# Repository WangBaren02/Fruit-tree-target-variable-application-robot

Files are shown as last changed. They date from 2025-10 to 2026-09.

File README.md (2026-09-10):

# 果树对靶变量施药机器人

*Fruit Tree Targeted Variable-Rate Application Robot*

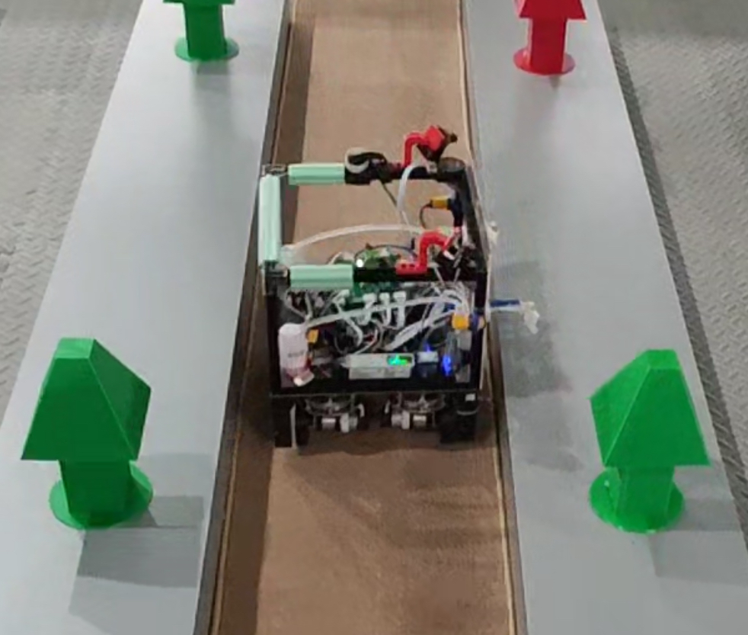
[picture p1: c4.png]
果树对靶变量施药机器人实机图片


## 项目简介

本项目面向果园植保作业场景，设计并实现了一套集自主移动、多传感器环境感知、目标视觉识别与变量施药于一体的农业机器人系统。系统采用 **STM32F407 + STM32F103 双控制器架构**：STM32F407 负责移动底盘、航向保持、行间运动与作业阶段调度，STM32F103 负责接收视觉/光电检测状态并驱动靶向施药机构。

移动底盘通过 **WitMotion IMU、6 路 Ultrasonic、Encoder 以及光电输入**获取姿态、环境距离、位移和行间状态，结合周期任务、作业状态机与 PID 完成前进、减速、换行和方向纠偏。作业端使用左右两个 OpenMV 脚本进行 **RGB565 图像采集、ROI 限定、颜色阈值分割和 Blob Detection**，将红/绿目标状态输出为 GPIO 信号；STM32F103 再根据作业侧、光电触发和目标颜色选择水泵组合及开启时间，实现面向目标类别的定时变量施药。

这个项目的核心不是把传感器简单堆叠在一块控制板上，而是把机器人拆分为三个相互协同的控制环节：

- **STM32F407**：解决机器人怎么移动、怎么保持方向、怎么减速和怎么换行；
- **OpenMV**：解决当前作业侧是否检测到红色/绿色目标；
- **STM32F103 + 水泵/舵机**：解决是否作业、对哪一侧作业以及采用哪一种施药时序。

## 项目亮点

- STM32F407 与 STM32F103 分工明确的双 MCU 分层控制；
- 基于 WitMotion 航向反馈、Ultrasonic 距离和 Encoder 位移的移动控制；
- TIM7 周期任务调度、`flag_step` 作业状态机和多组 PID 控制；
- OpenMV 基于颜色阈值、ROI 和最大 Blob 的轻量级目标识别；
- F407 通过 GPIO 状态信号向 F103 传递左右作业侧与作业使能状态；
- F103 使用光电边沿触发作业，并通过上下水泵的组合与开启时长区分红/绿目标的施药策略；
- 仓库同时保留自研 PCB 工程和 SolidWorks 机械设计资料。

## 技术栈与系统边界

| 子系统 | 已从工程中确认的实现 |
| --- | --- |
| 移动主控 | STM32F407VG、TIM7 周期调度、`flag_step` 状态机、PWM/GPIO |
| 作业控制器 | STM32F103RC、`WORK_FLAG`、左右选择、光电触发、泵/舵机控制 |
| 姿态/航向 | WitMotion 串口数据经 USART2 DMA 接收，解析 yaw；源码中的 `PID_9250_*` 为历史命名 |
| 距离感知 | 6 路 Ultrasonic：左/右侧各两路、前方两路 |
| 位移感知 | 当前 F407 软件初始化并读取 TIM3、TIM5 两路 Encoder 接口 |
| 光电输入 | F407 两路本地行间输入用于运动停行；F103 两路作业光电输入（PC4/PC9）用于目标经过触发 |
| 机器视觉 | 左、右两个 OpenMV 脚本；RGB565、QVGA、ROI、颜色阈值、最大 Blob |
| 底盘执行 | 4 路电机 PWM 与 4 路运动舵机输出 |
| 作业执行 | 1 路当前主循环使用的作业舵机输出、上下两路水泵、光电输入 |
| 工程资料 | PCB 工程压缩包、SolidWorks 零件/装配相关导出文件、STL/DWG/3MF 等 |

## 系统总体架构

```mermaid
flowchart TB
    env["果树目标与垄间环境"] --> perception["多源感知"]

    subgraph move["移动控制域 — STM32F407"]
        imu["WitMotion IMU<br/>USART2 DMA → yaw"]
        ultra["6 路 Ultrasonic"]
        enc["2 路 Encoder 接口"]
        localphoto["F407 光电输入"]
        f407logic["TIM7 周期任务<br/>flag_step 状态机 + PID"]
        imu --> f407logic
        ultra --> f407logic
        enc --> f407logic
        localphoto --> f407logic
        f407logic --> drive["4 路电机 PWM<br/>4 路运动舵机"]
    end

    subgraph vision["视觉感知域 — OpenMV"]
        leftcam["左 OpenMV 脚本"]
        rightcam["右 OpenMV 脚本"]
        visualgpio["红/绿 GPIO 状态"]
        leftcam --> visualgpio
        rightcam --> visualgpio
    end

    subgraph work["作业控制域 — STM32F103"]
        f103logic["WORK_FLAG + Select_LR<br/>Light_Detect + Select_Color"]
        strategy["红/绿目标施药策略"]
        workact["作业舵机<br/>上/下水泵"]
        f103logic --> strategy --> workact
    end

    perception --> imu
    perception --> ultra
    perception --> enc
    perception --> localphoto
    perception --> leftcam
    perception --> rightcam
    f407logic -- "PE7/PE8：左右作业侧<br/>PE14：作业使能" --> f103logic
    visualgpio -- "GPIO 红/绿状态" --> f103logic
    f103logic -- "PB7 → F407 PE15：减速反馈" --> f407logic
```

当前工程中，F407 与 F103 的实际协同路径是 GPIO 状态信号，而不是已经在主循环中启用的 UART 数据包协议：F407 使用 `PE7/PE8` 表示左右作业侧，使用 `PE14` 表示作业使能；F103 通过 `PB4/PB5/PB6` 读取这些状态，并通过 `PB7` 向 F407 回传减速信号。

## 双控制器协同架构

### STM32F407：移动底盘主控

F407 工程的 `USER/main.c` 完成底盘控制所需外设初始化，`SYSTEM/CONTROL/control.c` 中的 `TIM7_IRQHandler()` 负责周期性调度。当前源码可以恢复出以下职责链：

1. 通过 USART2 DMA 接收姿态串口帧，解析并更新 `yaw`；
2. 通过 6 路 Ultrasonic 获取前方和左右侧距离；
3. 通过 TIM3、TIM5 两路 Encoder 接口读取计数，并在换行流程中使用位移量；
4. 依据 `flag_step` 在前进、减速、左右转向、倒车和出垄等阶段之间切换；
5. 使用距离误差和 yaw 误差选择相应 PID，更新电机速度修正量与运动舵机角度；
6. 在不同作业阶段通过 `PE7/PE8` 选择左右作业侧，在需要时通过 `PE14` 打开作业模式；
7. 读取 F103 通过 `PB7 → PE15` 回传的减速信号，在检测到目标/作业触发后降低底盘速度。

源码中 `Select_Servo_Angle()`、`Select_Motor_Speed()`、`Select_PID()`、`HuanLong()` 和 `ChuLong()` 共同构成移动任务的状态化控制路径。这里的“换行/换垄”是由超声波、光电状态、航向控制和 Encoder 位移共同参与的流程，而不是单一传感器触发的动作。

### STM32F103：靶向施药控制器

F103 工程的 `USER/main.c` 在 `WORK_FLAG` 有效时执行：

```text
WORK_FLAG
  → Select_LR()
  → Light_Detect()
  → servo1(0)
```

其中：

- `Select_LR()` 对 F407 传来的左右作业侧信号进行两次采样确认，形成 `flag_Left/flag_Right`；
- `Light_Detect()` 监测作业板上的左右光电输入，在目标经过时触发一次作业；
- `Select_Color()` 只读取当前作业侧对应的红/绿输入，并形成 `flag_Red/flag_Green`；
- `Water()` 根据目标颜色选择上下水泵的开启组合与持续时间；
- `Clear_RESET()` 在非作业阶段清除颜色状态、复位光电基准并关闭水泵；
- `servo1()` 是当前主循环实际调用的作业舵机位置输出，非作业状态调用 `servo1(270)`，作业状态调用 `servo1(0)`。

因此，F103 不是另一个独立的移动主控，而是一个围绕“作业侧选择—目标触发—施药执行”展开的专用控制器。

### F407 ↔ F103 板间信号

| 逻辑信号 | F407 端 | F103 端 | 代码语义 |
| --- | --- | --- | --- |
| 左作业侧 | `PE7` | `PB4` | `Left_Flag` |
| 右作业侧 | `PE8` | `PB5` | `Right_Flag` |
| 作业使能 | `PE14` | `PB6` | `WORK_FLAG` |
| 减速反馈 | `PE15` | `PB7` | `SlowDown`，由 F103 回传给 F407 |

`Detect_Flag_Mv()` 根据 F407 当前的 `flag_step` 设置左右作业侧信号；`HuanLong()` 在换行作业阶段拉高作业使能；F103 在光电检测到目标后拉高减速输出，F407 的 `Detect_Flag_Slowdown()` 再据此进入减速逻辑。当前代码能够确认的是这组 GPIO 级状态协同，不应把它包装成复杂的双向通信协议。

## 移动底盘控制

### 周期任务与状态机

F407 的 TIM7 中断以周期计数方式组织任务：5 ms 级别执行检测、减速判断、舵机角度选择、电机速度选择和 PID 选择；25 ms 级别触发 Ultrasonic；10 ms 级别发送 yaw 相关数据。`flag_step` 将整车动作拆分为前进、光电停行、左右换行、倒车和出垄等阶段。

### 航向、距离与位移反馈

- **WitMotion 航向反馈**：`HARDWARE/USART2_DMA/usart2_dma.c` 从 USART2 DMA 缓冲区解析 `0x55 0x53` 姿态帧，得到相对起始航向的 `yaw`；
- **距离反馈**：`HARDWARE/ULTRASONIC/` 中维护 `ultra_L1/L2`、`ultra_R1/R2`、`ultra_F1/F2` 六路测距量，并在不同运动阶段选择侧向或前向距离误差；
- **位移反馈**：`HARDWARE/ENCODER/` 当前初始化 TIM3、TIM5 两个 Encoder 接口，`Read_Encoder_Cnt()` 将计数换算为 `Encoders.disA/disB`，主要服务于换行/倒车距离流程；
- **执行输出**：`HARDWARE/MOTOR/` 提供 4 路电机 PWM 与方向控制，`HARDWARE/SERVO/` 当前运动路径使用 4 路舵机 PWM。

旧版说明中的“6 encoders”没有得到当前 F407 软件读取路径的支持。README 采用源码能确认的“两路 Encoder 接口”，不把可能存在的机械配置数量与软件实际读取数量混为一谈。

### 移动控制闭环

```mermaid
flowchart LR
    imu["WitMotion yaw"] --> heading["航向误差 / PID"]
    ultra["6 路 Ultrasonic"] --> distance["距离误差 / PID"]
    enc["TIM3 + TIM5 Encoder"] --> row["换行位移判断"]
    heading --> control["运动控制策略"]
    distance --> control
    row --> control
    control --> output["4 路电机 PWM<br/>4 路运动舵机"]
    output --> robot["移动底盘"]
    robot -. "姿态/距离/位移反馈" .-> imu
    robot -. "姿态/距离/位移反馈" .-> ultra
    robot -. "姿态/距离/位移反馈" .-> enc
```

## 靶向变量施药

### 变量由什么控制

当前源码所体现的“变量”不是由流量传感器构成的连续流量闭环，而是由以下离散策略共同决定：

1. **目标类别**：OpenMV 输出红色或绿色状态；
2. **作业侧**：F407 通过 `PE7/PE8` 告知 F103 当前执行左侧还是右侧机构；
3. **触发时刻**：F103 的左右光电输入检测到目标经过的边沿后启动一次作业；
4. **泵组合与开启时间**：`Water()` 按红/绿状态控制上、下两路水泵及其延时常量。

在当前 `sow.c` 中，代码逻辑可以概括为：

| 目标状态 | 当前代码中的执行策略 |
| --- | --- |
| 绿色 | 下路水泵开启，保持 `BiuBiu_time_Green` 对应的延时后关闭 |
| 红色 | 上路水泵先开启 `BiuBiu_time_UP` 对应的延时，再开启下路水泵并保持 `BiuBiu_time_DOWN` 对应的延时 |

因此，本项目的变量施药应准确表述为：**基于目标颜色分类的双水泵组合与定时控制**。代码中没有发现流量传感器、压力反馈或基于 Blob 面积连续调节泵时长的闭环；Blob 面积在 OpenMV 中用于筛选有效目标和选取最大 Blob，当前并未直接映射为施药量。

### 靶向施药控制流程

```mermaid
flowchart TD
    camera["左/右 OpenMV"] --> image["RGB565 图像 + ROI"]
    image --> blob["颜色阈值 + Blob Detection<br/>选取最大 Blob"]
    blob --> color["红/绿 GPIO 状态"]

    side["F407 PE7/PE8<br/>左右作业侧"] --> f103["STM32F103"]
    workflag["F407 PE14 → PB6<br/>WORK_FLAG"] --> f103
    color --> f103
    photo["F103 PC4/PC9<br/>左右光电输入"] --> edge["Light_Detect 光电边沿"]
    f103 --> edge
    edge --> select["Select_LR + Select_Color"]
    select --> delay["按作业侧等待<br/>Deteted2Biu_Left/Right"]
    delay --> strategy{"目标类别"}
    strategy -->|绿色| green["Pump_Down<br/>按 Green 时长开启"]
    strategy -->|红色| red["Pump_Up → Pump_Down<br/>按 UP/DOWN 时长顺序开启"]
    green --> clear["关闭水泵并清除本次状态"]
    red --> clear
    f103 -. "PB7 SlowDown" .-> slow["F407 PE15<br/>底盘减速"]
```

## 机器视觉

仓库中的 `OpenMV/left.txt` 和 `OpenMV/rught.txt` 分别对应左、右作业侧脚本。两份脚本的当前有效路径具有相同的基本结构：

- 使用 `RGB565`、`QVGA` 图像格式，并关闭自动增益和自动白平衡；
- 只在预设 ROI 内搜索目标，减少整幅图像处理范围；
- 使用绿色和红色 Color Threshold 查找 Blob；
- 以 `pixels()` 选择面积最大的候选 Blob；
- 将绿色/红色识别结果通过 GPIO 输出给 F103 的输入端。

当前有效代码不是神经网络、YOLO 或深度学习模型。脚本中虽然保留了 UART 导入和“双目标”相关的注释/变量，但当前工作路径实际使用的是红/绿 GPIO 状态；`double` 输出逻辑没有形成已启用的独立目标类别。

## 自动作业流程

```text
F407 进入对应 flag_step
        ↓
通过 PE7 / PE8 告知 F103 当前左右作业侧
        ↓
在作业阶段通过 PE14 置位 WORK_FLAG
        ↓
F103 读取当前侧 OpenMV 红/绿 GPIO 状态
        ↓
左右光电输入出现目标经过边沿
        ↓
按作业侧延时后执行 Select_Color / Water
        ↓
根据红/绿状态选择上下水泵组合和开启时间
        ↓
F103 通过 PB7 回传减速状态，F407 降低底盘速度
        ↓
关闭水泵、清除本次状态，等待下一目标
```

## 硬件与机械设计

仓库同时包含机器人硬件和机械设计资料：

- `第十届农装PCB工程.epro`：PCB 工程压缩包，内部包含多份 PCB 布局、原理图、封装和符号资源；
- `SW文件/`：包含相机支架、超声波支架、树体/亚克力结构、施药机构以及齿轮、链条、舵机等相关机械设计或导出文件；
- `c4.png`：现有机器人实机/比赛场景图片。

本 README 只描述能够从工程结构和源码中确认的系统关系，不把无法从当前资料完整核实的电路细节、喷头流量或机械尺寸扩展成性能结论。

## 软件结构

目录保持仓库原有组织方式，未对源码进行移动、重命名或重构：

```text
.
├── 正赛主控代码/        # STM32F407 移动底盘主控工程
│   ├── CORE/
│   ├── DMP/
│   ├── FWLIB/
│   ├── HARDWARE/
│   ├── SYSTEM/
│   └── USER/
├── 正赛作业代码/        # STM32F103 靶向施药控制工程
│   ├── CORE/
│   ├── HARDWARE/
│   ├── STM32F10x_FWLib/
│   ├── SYSTEM/
│   └── USER/
├── OpenMV/              # 左/右视觉脚本
├── SW文件/              # 机械设计及导出资料
├── 第十届农装PCB工程.epro # PCB 工程
├── c4.png              # 实机图片
├── README.md
└── LICENSE
```

### F407 工程模块

- `USER/`：启动入口和主循环；
- `SYSTEM/CONTROL/`：TIM7 周期调度、移动任务状态机、行间动作和作业板信号；
- `SYSTEM/PID/`：距离/航向等运动控制器；
- `HARDWARE/MOTOR/`：4 路电机 PWM 与方向控制；
- `HARDWARE/SERVO/`：运动舵机 PWM；
- `HARDWARE/ENCODER/`：TIM3/TIM5 Encoder 接口和位移读取；
- `HARDWARE/ULTRASONIC/`：6 路 Ultrasonic 触发、捕获和滤波；
- `HARDWARE/USART2_DMA/`：姿态串口 DMA 接收与 yaw 解析；
- `HARDWARE/IO/`：本地光电输入及 F407/F103 板间 GPIO。

### F103 工程模块

- `USER/`：作业控制主循环；
- `HARDWARE/SOW/`：左右选择、颜色判断、光电触发、泵控制、作业状态清理；
- `HARDWARE/IO/`：OpenMV 红/绿输入、光电输入、泵输出及板间信号；
- `HARDWARE/PWM/`：作业舵机 PWM；
- `HARDWARE/TIMER/`、`HARDWARE/KEY/`：定时和按键/调试相关功能；
- `HARDWARE/UART/`：仓库中保留的 OpenMV 串口解析模块，当前 `main.c` 未将其接入有效作业主流程。

## 项目演示

[▶ 点击观看果树对靶变量施药机器人实机演示](https://www.bilibili.com/video/BV1MZybBGE1s?vd_source=f2363d1b121157b15409b799183edefd)

## 比赛背景

本项目对应 **“天鹅杯”第十届国际大学生智能农业装备创新大赛 B 类（机器人类）** 的果树对靶变量施药机器人作品。比赛背景资料可参见：[“天鹅杯”第十届国际大学生智能农业装备创新大赛通知](https://uiaec.ujs.edu.cn/news_show.php?id=215)。

## 实现边界与历史命名说明

- F407 工程中存在 `MPU9250`、`MPUIIC`、DMP 以及 `PID_9250_*` 等历史目录、宏和函数名；当前 README 按实际机器人使用的 **WitMotion IMU** 及 `USART2_DMA` 的 yaw 解析路径描述，不修改这些历史命名；
- F407 工程还保留 `wit_c_sdk`、TFLuna 等模块，但它们不能仅凭存在于目录中就视为当前主控制链路的一部分；
- F103 工程保留 TCS3200、JAINSU 以及 OpenMV UART 帧解析等旧/备用模块，当前有效作业主循环使用的是 GPIO 红/绿输入和光电输入；
- 仓库中的历史代码、注释、备用模块和旧工程配置均未在本次工作中清理或重构。

## License

本项目许可证信息请参见仓库中的 [`LICENSE`](./LICENSE) 文件。

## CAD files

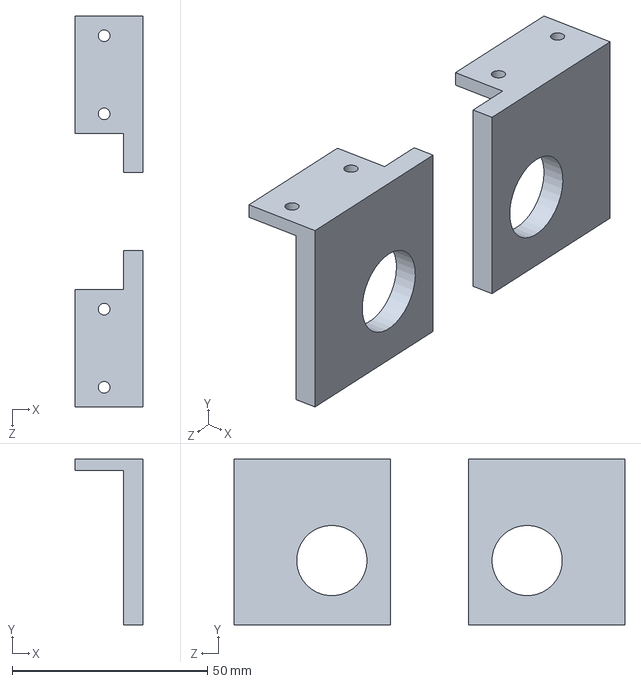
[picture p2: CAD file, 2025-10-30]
SW文件/光电管/光电管支架1cm.SLDPRT
17.5 x 42.5 x 100.0 mm

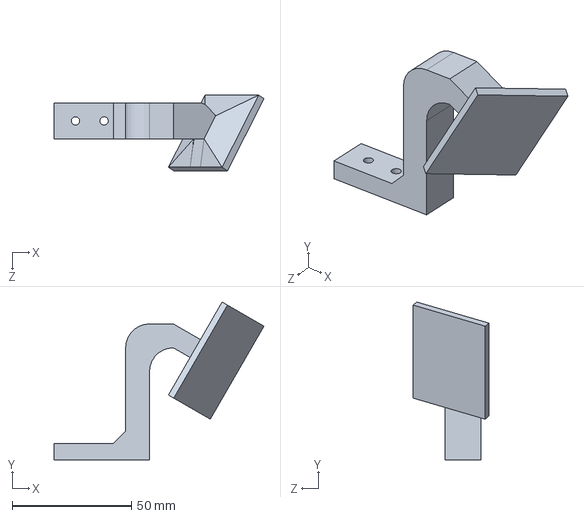
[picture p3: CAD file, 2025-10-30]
SW文件/摄像头（不可调）/摄像头左.SLDPRT
88.0 x 66.2 x 31.7 mm

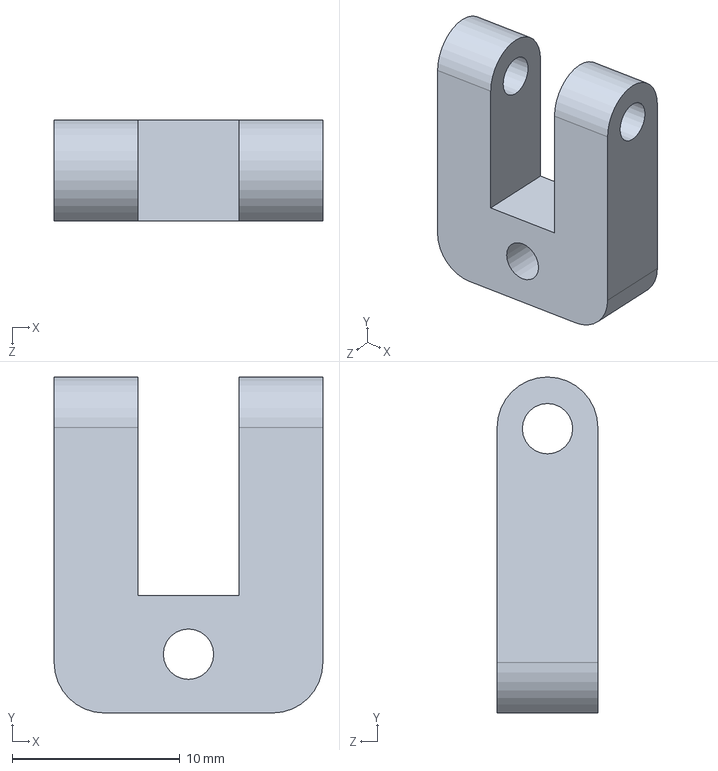
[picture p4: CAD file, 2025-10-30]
SW文件/摄像头（可调）/摄像头支架.SLDPRT
16.0 x 20.0 x 6.00 mm

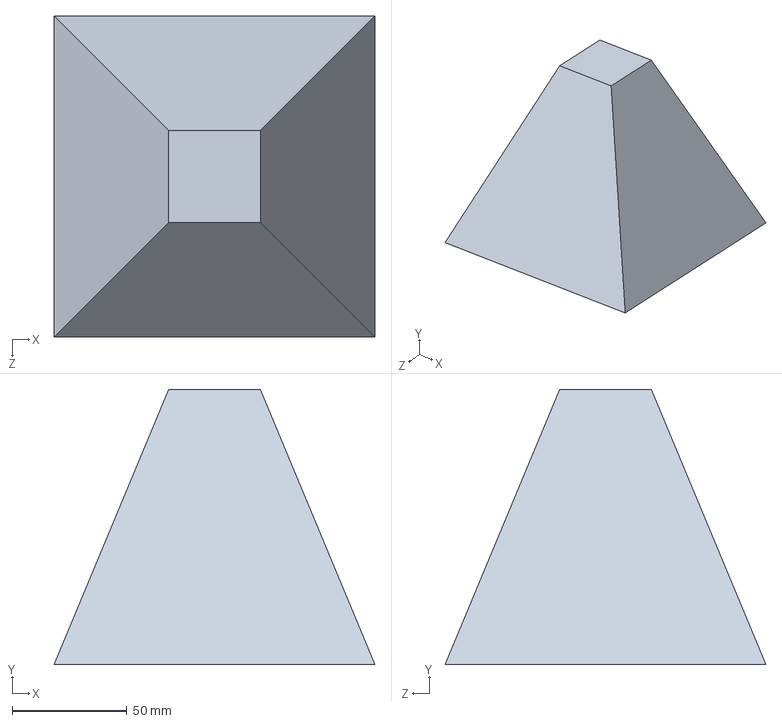
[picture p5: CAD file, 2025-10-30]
SW文件/树/树冠.SLDPRT
140.0 x 120.0 x 140.0 mm

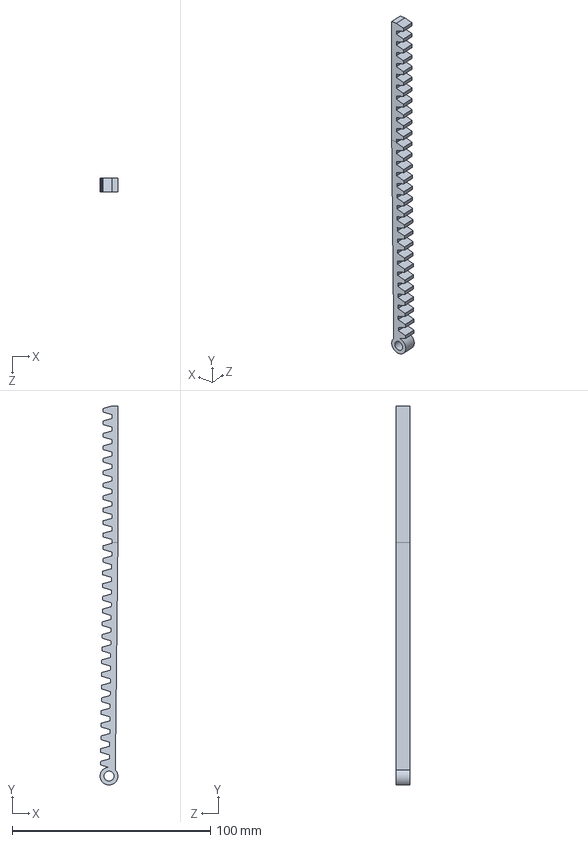
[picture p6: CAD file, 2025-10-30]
SW文件/线性执行器/链条.SLDPRT
8.99 x 191.3 x 7.00 mm

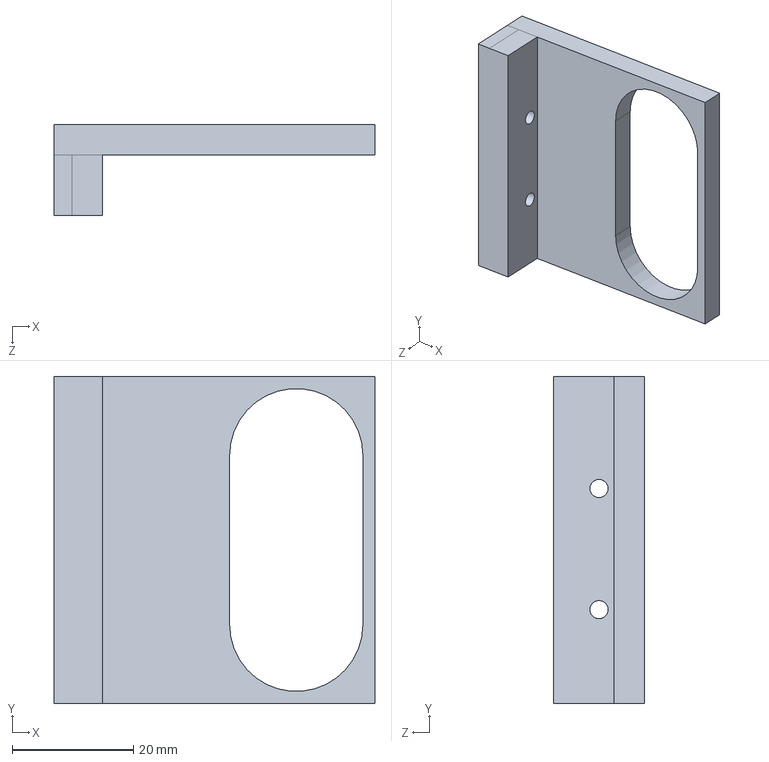
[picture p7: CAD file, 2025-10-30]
SW文件/超声波支架/超声波支架前1.SLDPRT
53.0 x 54.0 x 15.0 mm

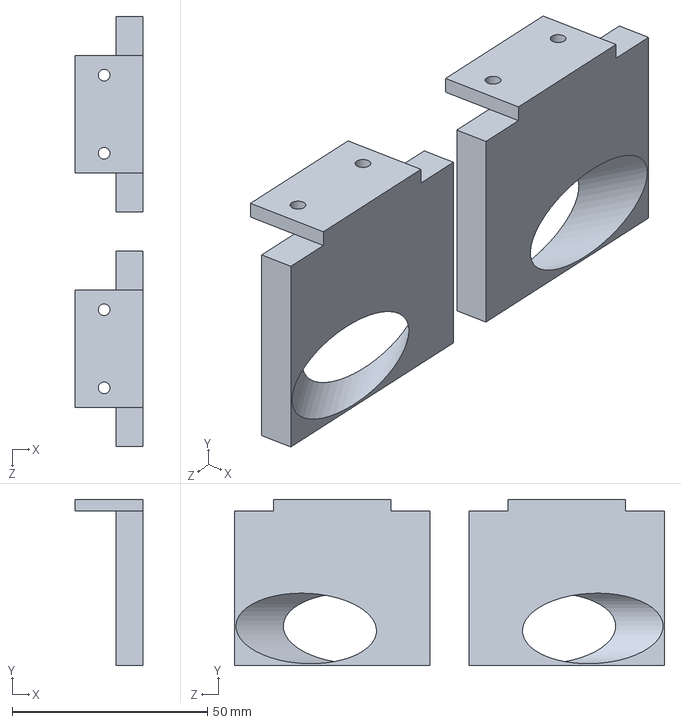
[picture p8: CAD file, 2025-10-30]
SW文件/光电管/光电管支架 60°椭圆.SLDPRT
17.5 x 42.5 x 110.0 mm

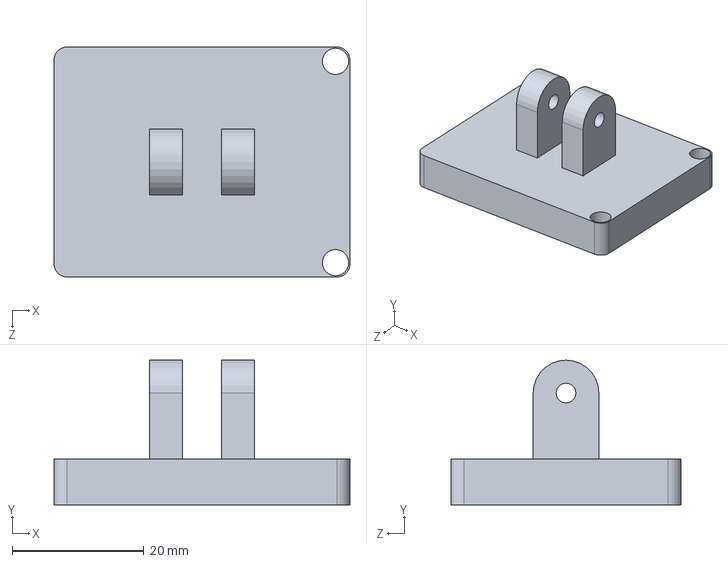
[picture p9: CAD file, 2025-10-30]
SW文件/摄像头（可调）/摄像头支架2.SLDPRT
45.0 x 22.0 x 35.0 mm

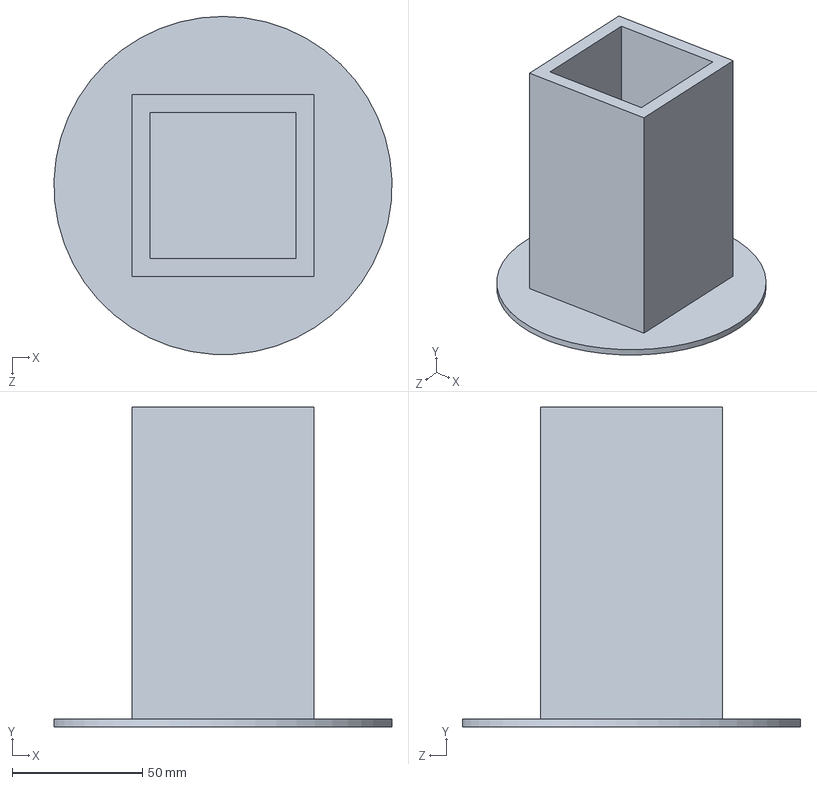
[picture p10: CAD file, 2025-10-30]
SW文件/树/树干.SLDPRT
129.9 x 123.0 x 130.0 mm

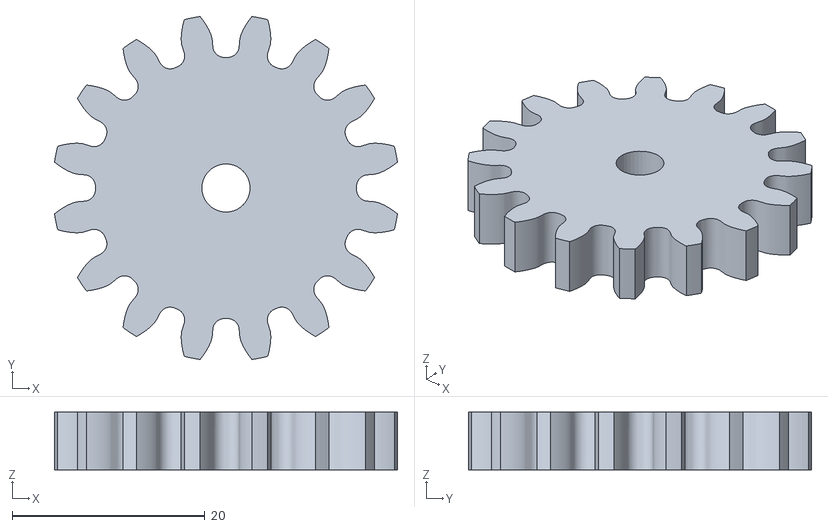
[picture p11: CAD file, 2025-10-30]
SW文件/线性执行器/齿轮小.STL
35.6 x 35.6 x 6.00

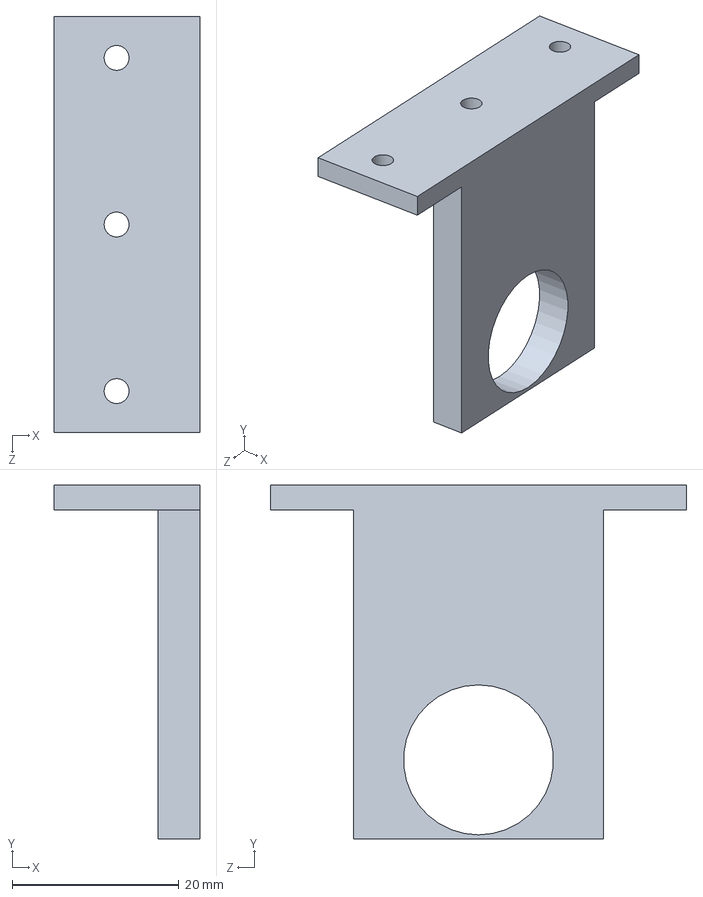
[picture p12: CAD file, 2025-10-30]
SW文件/光电管/光电管支架2.SLDPRT
17.5 x 42.5 x 50.0 mm

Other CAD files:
SW文件/不锈钢底板/不锈钢底板1.SLDPRT
SW文件/亚克力板/喷头亚克力板.SLDPRT
SW文件/不锈钢底板/不锈钢底板.SLDPRT
SW文件/亚克力板/圆盘.DWG
SW文件/摄像头（不可调）/摄像头右.SLDPRT
SW文件/超声波支架/超声波支架前2.SLDPRT
SW文件/亚克力板/亚克力左.SLDPRT
SW文件/亚克力板/不锈钢底板.DWG
SW文件/亚克力板/不锈钢底板.SLDPRT
SW文件/亚克力板/亚克力右.DWG
SW文件/亚克力板/亚克力右.SLDPRT
SW文件/亚克力板/亚克力左.DWG
SW文件/亚克力板/亚克力板.DWG
SW文件/亚克力板/亚克力板.SLDPRT
SW文件/亚克力板/喷头亚克力板.DWG
SW文件/光电管/光电管支架 - 副本 - 副本 - 副本.SLDPRT
SW文件/光电管/光电管支架 - 副本 - 副本.SLDPRT
SW文件/光电管/光电管支架 45°.SLDPRT
SW文件/光电管/光电管支架 45°.STL
SW文件/光电管/光电管支架 45°2 - 副本.SLDPRT
SW文件/光电管/光电管支架 45°2.SLDPRT
SW文件/光电管/光电管支架 45°2.STL
SW文件/光电管/光电管支架 45°椭圆.SLDPRT
SW文件/光电管/光电管支架 45°椭圆.STL
SW文件/光电管/光电管支架 60°椭圆.STL
SW文件/光电管/光电管支架1cm.STL
SW文件/光电管/光电管支架2.3mf
SW文件/光电管/光电管支架2.STL
SW文件/光电管/光电管支架2cm.SLDPRT
SW文件/光电管/光电管支架2cm.STL
SW文件/光电管/光电管支架短.STL
SW文件/光电管/光电管支架长.STL
SW文件/摄像头（不可调）/摄像头右.STL
SW文件/摄像头（不可调）/摄像头左.STL
SW文件/摄像头（可调）/摄像头支架.STL
SW文件/摄像头（可调）/摄像头支架2.STL
SW文件/树/树冠.STL
SW文件/树/树冠2.STL
SW文件/树/树干.STL
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

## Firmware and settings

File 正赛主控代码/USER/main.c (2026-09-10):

#include "stdio.h"
#include "string.h"
#include "sys.h"
#include "delay.h"
#include "stm32f4xx.h"
#include "control.h"
//#include "lamp.h"
#include "led.h"
#include "beep.h"
#include "key.h"
#include "oled.h"
#include "usart1_dma.h"
#include "usart2_dma.h"
#include "usart3_dma.h"
#include "uart4_dma.h"
#include "timer7.h"
#include "servo.h"
#include "ultrasonic.h"
#include "motor.h"
#include "encoder.h"
#include "pid.h"
#include "io.h"

float start_yaw=0;

int main(void)
{
	//系统初始化
	u8 key;
	u8 Add_Encoder_Flag = 0;
	float Add_Encoder_Oled = 0;
	float yaw_t;
	NVIC_PriorityGroupConfig(NVIC_PriorityGroup_2);
	delay_init(168);
	//BEEP_Init();
	Key_Init();
	IO_init();
	LED_Init();
	TIM4_Servo_PWM_Init(20000,84);
	Ultrasonic_Init();
	OLED_Init();
	OLED_Display_On();
	
	OLED_Clear();
	Motor_Init();
	TIM7_Init(1000,84);
	TIM3_EncoderB_Init(0xFFFF,1);
	TIM5_EncoderA_Init(0xFFFF,1);
	PID_Init();
	Motor_Stop();
	Motor_Set_Speed();
	USART1_Init(115200);	//单片机与陀螺仪上位机通讯串口
	USART2_Init(9600);		//单片机与陀螺仪通讯串口

	Servo1_Increase = 0;
	Servo2_Increase = 0;
	Servo3_Increase = 0;
	Servo4_Increase = 0;
	SpeedL1_Increase = 0;
	SpeedR1_Increase = 0;
	SpeedL2_Increase = 0;
	SpeedR2_Increase = 0;
	SpeedL1_Increase_9250 = 0;
	SpeedR1_Increase_9250 = 0;
	SpeedL2_Increase_9250 = 0;
	SpeedR2_Increase_9250 = 0;
//	LED1_ON;
	
	Servo_Forw();
//	Servo_Turn();
	Servo_Set_Angle();
	while(1)
	{
		key = Key_Scan();
		if(key == 1)	//尽量不要改里面的东西，看懂了再改
		{
			start_YAW=yaw;					//记录下当前指南针原始中心角度
			if(start_YAW>-180 && start_YAW<-135) mode=2;
			else if(start_YAW<180 && start_YAW>135) mode=3;

			delay_ms(100);			//等待yaw稳定
			
			start_yaw=yaw;
			PID_9250_Forward_motor.desired = start_yaw;
			PID_9250_Forward.desired = start_yaw;
			PID_9250_Right.desired = start_yaw;
			PID_9250_Left.desired = start_yaw;
			PID_9250_Right_slow.desired = start_yaw;
			PID_9250_Left_slow.desired = start_yaw;
			PID_9250_Back.desired = start_yaw;
			PID_9250_Back_last.desired = start_yaw;
			PID_9250_Back_last_motor.desired = start_yaw;
			
			GPIO_ResetBits(GPIOE,GPIO_Pin_14);	//板间通讯，给作业板关闭作业模式信号
			
			flag_mission_start = 1;
			flag_delay_1500ms = 1;	//step0时开始2s后以75%速度继续行驶
		}
		
		if(key == 2)
		{
//			switch (Add_Encoder_Flag)
//			{
//				case 1: Add_Encoder_2 	+= 1.8; Add_Encoder_Oled += 1.8; break;
//				case 2: Add_Encoder_4 	+= 1.6; Add_Encoder_Oled += 1.6; break;
//				case 3: Add_Encoder_6 	+= 1.8; Add_Encoder_Oled += 1.8; break;
//				case 4: Add_Encoder_8 	+= 1.6; Add_Encoder_Oled += 1.6; break;
//				case 5: Add_Encoder_10 	+= 1.8; Add_Encoder_Oled += 1.8; break;
//				case 6: Add_Encoder_Last+= 2.0; Add_Encoder_Oled += 2.0; break;
//				default:;
//			}
////调编码器用		
//			switch (Add_Encoder_Flag)
//			{
//				case 1: Add_Encoder_2 	-= 0.3; Add_Encoder_Oled -= 0.3; break;
//				case 2: Add_Encoder_4 	-= 0.2; Add_Encoder_Oled -= 0.2; break;
//				case 3: Add_Encoder_6 	-= 0.3; Add_Encoder_Oled -= 0.3; break;
//				case 4: Add_Encoder_8 	-= 0.2; Add_Encoder_Oled -= 0.2; break;
//				case 5: Add_Encoder_10 	-= 0.3; Add_Encoder_Oled -= 0.3; break;
//				case 6: Add_Encoder_Last-= 1.0; Add_Encoder_Oled -= 1.0; break;
//				default:;
//			}
			
			switch (Add_Encoder_Flag)
			{
				case 1: Add_Encoder_2 	+= 0.3; Add_Encoder_Oled += 0.3; break;
				case 2: Add_Encoder_4 	+= 0.2; Add_Encoder_Oled += 0.2; break;
				case 3: Add_Encoder_6 	+= 0.3; Add_Encoder_Oled += 0.3; break;
				case 4: Add_Encoder_8 	+= 0.2; Add_Encoder_Oled += 0.2; break;
				case 5: Add_Encoder_10 	+= 0.3; Add_Encoder_Oled += 0.3; break;
				case 6: Add_Encoder_Last+= 1.0; Add_Encoder_Oled += 1.0; break;
				default:;
			}
			
//			PID_F1_Right_Servo.kd +=0.1;
//			PID_F2_Right_Servo.kd +=0.1;
//			PID_F1_Right_Servo.kd += 0.1;
//			PID_F2_Right_Servo.kd += 0.1;
//			flag_step += 2;
//			PID_9250_Right.kd+=100;
//			PID_F1_Left_Servo.kp+=0.1;
//			PID_F1_Left_Servo.kp+=0.1;
		}
		
		if(key == 3)
		{
			if(Add_Encoder_Flag < 6)
			{
				Add_Encoder_Flag ++;
			}
			else if(Add_Encoder_Flag == 6)
			{
				Add_Encoder_Flag = 0;
			}
			Add_Encoder_Oled = 0; 
//			PID_9250_Right.kd+=50;
//			PID_F1_Right_Servo.kd +=0.05;
//			PID_F2_Right_Servo.kd +=0.05;
//			PID_F1_Right_Servo.kd += 0.05;
//			PID_F2_Right_Servo.kd += 0.05;
//			start_YAW=yaw;					//记录下当前指南针原始中心角度
//			if(start_YAW>-180 && start_YAW<-135)mode=2;
//			else if(start_YAW<180 && start_YAW>135)mode=3;
//			PID_9250_Right.kd+=2;
		}
		
		if(key == 4)
		{
			switch (Add_Encoder_Flag)
			{
				case 1: Add_Encoder_2 	+= 0.8; Add_Encoder_Oled += 0.8; break;
				case 2: Add_Encoder_4 	+= 0.55; Add_Encoder_Oled += 0.55; break;
				case 3: Add_Encoder_6 	+= 0.8; Add_Encoder_Oled += 0.8; break;
				case 4: Add_Encoder_8 	+= 0.55; Add_Encoder_Oled += 0.55; break;
				case 5: Add_Encoder_10 	+= 0.8; Add_Encoder_Oled += 0.8; break;
				case 6: Add_Encoder_Last+= 2.0; Add_Encoder_Oled += 2.0; break;
				default:;
			}
//			PID_9250_Right.kd+=10;
//			PID_F1_Right_Servo.kd +=0.01;
//			PID_F2_Right_Servo.kd +=0.01;
//			PID_F1_Right_Servo.kd += 0.01;
//			PID_F2_Right_Servo.kd += 0.01;
//			delay_ms(100);
//			Motor_Forw();
//			Motor_Right();
//			Motor_Left();
//			Motor_Back();
//			Motor_Set_Speed();
//			Servo_Forw();
//			Servo_Set_Angle();
		}
		
		
		delay_us(20);
//		OLED_Show3FNum(10,0,yaw ,4,2,12);
//		OLED_ShowIntNum(64,0,flag_step,2,12);
		//OLED_ShowIntNum(84,0,flag_huanlong,1,12);
		//OLED_ShowIntNum(96,0,flag_chulong,1,12);
		
//		OLED_Show3FNum(64,0 ,	PID_9250_Back.kp,3,1,12);
//		OLED_Show3FNum(10,12 ,	PID_9250_Back.kd,3,1,12);
		
		
//		OLED_Show3FNum(0,36,PID_9250_Right.kp,5,2,12);
//		OLED_Show3FNum(48,36,PID_9250_Right.kd,5,2,12);
/*********************************************************/
		OLED_Show3FNum(60,36,ultra_F1.DIS ,5,2,12);	//接口5
		OLED_Show3FNum(0,36,ultra_F2.DIS ,5,2,12);	//接口6

		OLED_Show3FNum(60,24,ultra_L1.DIS ,5,2,12);	//接口1
		OLED_Show3FNum(60,12,ultra_L2.DIS,5,2,12);	//接口2
		
		OLED_Show3FNum(0,24,ultra_R1.DIS ,5,2,12);	//接口3
		OLED_Show3FNum(0,12,ultra_R2.DIS ,5,2,12);	//接口4
		
//		OLED_Show3FNum(0,48,PID_F1_Right_Servo.kp ,5,2,12);
//		OLED_Show3FNum(60,48,PID_F1_Right_Servo.kd ,5,2,12);
		OLED_Show3FNum(0,48,Add_Encoder_Flag ,5,2,12);
		OLED_Show3FNum(60,48,Add_Encoder_Oled ,5,2,12);
    
//		OLED_Show3FNum(10,48,RightLightLast ,1,0,12);
//		OLED_Show3FNum(24,48,LeftLightLast ,1,0,12);
//		OLED_Show3FNum(36,48,RightLight ,1,0,12);
//		OLED_Show3FNum(48,48,LeftLight ,1,0,12);
//		OLED_Show3FNum(10,48,PID_F1_Left_Servo.kp ,1,3,12);
//		OLED_Show3FNum(48,48,PID_F1_Left_Servo.kd ,1,3,12);
	  OLED_Refresh_Gram();
	}
}

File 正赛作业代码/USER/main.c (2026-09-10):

#include "delay.h"
#include "sys.h"
#include "bmp.h"
#include "stdio.h"
#include "io.h"
#include "pwm.h"
#include "timer.h"
#include "key.h"
#include "sow.h"

int main(void)
{
		u8 key;
		IO_Init();
	  NVIC_PriorityGroupConfig(NVIC_PriorityGroup_2);   //设置NVIC中断分组2:2位抢占优先级，2位响应优先级
		TIM5_PWM_Init(20000,72);
		delay_init();	 //延时函数初始化:	有问题，延迟时间大概是八分之一，最长24000（3s） 

			while(1)
			{
				key = KEY_Scan(0);

				//正式比赛
				if(WORK_FLAG)
				{
					Select_LR();
					Light_Detect();
					servo1(0);
				}
				else
				{
					Clear_RESET();
					servo1(270);
				}
				
				
				 //摄像头颜色测试				
         if ((Right_red) && (!Right_green))
				 {
						Led1_ON;  
						Led2_ON;  
				 }
				 else if ((!Right_red) && (Right_green))
				 {
						Led1_ON;  
				 }
				 else
				 {
						Led1_OFF;  
						Led2_OFF; 
				 }
				
//				//舵机测试				
//				if(key == KEY_B9_PRES)
//				{
//					servo1(270);
//					Led1_ON;
//				}
//				
//				if(key == KEY_C13_PRES)
//				{
//					servo1(0);
//					Led1_OFF;
//				}
				
				//喷水测试				
				if(key == KEY_B9_PRES)
				{
//					Pump_Down_ON;								//开启下水泵
//					Pump_Up_ON;									//开启上水泵
//								
//					delay_ms(BiuBiu_time_UP);		//下水泵喷水时长
//					Pump_Down_OFF;							//关闭下水泵
//							
//					delay_ms(BiuBiu_interval);	//上水泵多于下水泵的喷水时长
//					Pump_Up_OFF;								//关闭上水泵
					
					
					Pump_Down_ON;									//开启下水泵
					delay_ms(BiuBiu_time_Green);	//下水泵喷水时长
					Pump_Down_OFF;								//关闭下水泵
				}
				
				if(key == KEY_C13_PRES)
				{
//					Pump_Up_ON;		//上水泵
//					Pump_Down_ON;;	//下水泵
//					delay_ms(200);	//上：8~9
//					Pump_Up_OFF;	//关闭上水泵
//					Pump_Down_OFF;							//关闭下水泵
////					Pump_Up_ON;			//上水泵
////					Pump_Down_ON;;	//下水泵
//					
//					
//					
					Pump_Up_ON;									//开启上水泵
					delay_ms(BiuBiu_time_UP);		//下水泵喷水时长
					Pump_Up_OFF;								//关闭下水泵
				}
				
//				//光电管测试
//				if(Light_Left)	//左侧光电管
//					Led1_ON;
//				else
//					Led1_OFF;
//				
//				if(Light_Right)	//右侧光电管
//					Led2_ON;
//				else
//					Led2_OFF;

//				//左右行检测				
//				if(flag_Right) Led1_ON;
//				else Led1_OFF;
//				
//				if(flag_Left) Led2_ON;
//				else Led2_OFF;
			
			}
}

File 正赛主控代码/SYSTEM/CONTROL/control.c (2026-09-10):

/*
2025 张瀚文
		        F1 头 F2
			   L1----------R1
				 |            |
				 |            |
				 |            |
				 |            |
				 |            |
				 |            |
				 |            |
				 |            |
				 |            |
				 L2---------- R2
				       尾 
*/
#include "stdio.h"
#include "string.h"
#include "control.h"
#include "sys.h"
#include "delay.h"
//#include "lamp.h"
#include "led.h"
#include "usart1_dma.h"
#include "usart2_dma.h"
#include "usart3_dma.h"
#include "uart4_dma.h"
#include "ultrasonic.h"
#include "oled.h"
#include "encoder.h"
#include "param.h"
#include "motor.h"
#include "pid.h"
#include "servo.h"
#include "io.h"

#define N 0.98
#define Move 180          //直行停车预留量 160
#define move 320          //右行停车预留量 320
#define movez 320         //左行停车预留量 320
#define movez_last 240		//出垄前左行停车预留量

u8 parity	= 0;								//判断奇数偶
float pitch, roll;
extern float yaw;
short aacx, aacy, aacz;
short gyrox, gyroy, gyroz;
u8 flag_step = 0;					//判断现在运行到了第几步的标志
u8 flag_yaw_new = 0;
float Add_Encoder_2 					= 0;
float Add_Encoder_4 					= 0;
float Add_Encoder_6 					= 0;
float Add_Encoder_8 					= 0;
float Add_Encoder_10 					= 0;
float Add_Encoder_Last 				= 0;

char PIDOUT[20];
//int a=0;
/***********************************张瀚文 2024********************************************
0： 入长垄          
1： 右行
2： 换垄
3： 左行
4： 换垄
5： 右行
6： 换垄
7： 左行
8： 换垄
9： 右行
10：换垄
11：左行
12：出垄
13：停车
***********************************************************************************************/
u8 flag_mission_start 		= 0;				//按键按下后，进入控制函数的标志
u8 flag_huanlong 				  = 0;				//换垄标志，此flag=1时正在换垄
u8 flag_chulong 				  = 0;				//出笼标志，此flag=1时已经出笼
u8 flag_slowdown 				  = 0;				//减速标志，此flag=1时表示需要减速
u8 flag_zuowuslowdown 		= 0;				//减速标志，此flag=1时表示需要减速
u8 flag_found_zuowu				= 0;				//检测作物的标志，此flag=1时表示检测到作物，开始减速
u8 flag_delay					    = 0;				//延时标志，此flag=1时表示需要延时
u8 flag_delay_200ms				= 0;				//延时标志，此flag=1时表示需要延时200ms
u8 flag_delay_500ms				= 0;				//延时标志，此flag=1时表示需要延时500ms
u8 flag_delay_1000ms			= 0;				//延时标志，此flag=1时表示需要延时1000ms
u8 flag_delay_1500ms			= 0;				//延时标志，此flag=1时表示需要延时1500ms
u8 flag_delay_zuowu				= 0;				//延时标志，此flag=1时作物表示需要延时
u8 Color_SLOW							= 0;
u8 flag_step0SLOW					= 0;
uint8_t RightLightLast = 2;
uint8_t LeftLightLast = 2;

//float N_F_R = 1.0;
//根据不同步数选择舵机、电机的基本角度、速度
float Servo1_Base = 135, Servo2_Base = 135, Servo3_Base = 135, Servo4_Base = 135;
float Servo5_Base = 0, Servo6_Base = 0, Servo7_Base = 0, Servo8_Base = 0;
float SpeedL1_Base = 0, SpeedR1_Base = 0, SpeedL2_Base = 0, SpeedR2_Base = 0;
float SpeedL1_Base_c = 0, SpeedR1_Base_c = 0, SpeedL2_Base_c = 0, SpeedR2_Base_c = 0;
//根据PID的结果得到的舵机、电机的增量
float Servo1_Increase = 0, Servo2_Increase = 0, Servo3_Increase = 0, Servo4_Increase = 0;
float Servo5_Increase = 0, Servo6_Increase = 0, Servo7_Increase = 0, Servo8_Increase = 0;
float SpeedL1_Increase = 0, SpeedR1_Increase = 0, SpeedL2_Increase = 0, SpeedR2_Increase = 0;
float SpeedL1_Increase_9250 = 0, SpeedR1_Increase_9250 = 0, SpeedL2_Increase_9250 = 0, SpeedR2_Increase_9250 = 0;
//调试基础电机速度
//float Motor_Forw_test_L1 = 0, Motor_Forw_test_L2 = 0, Motor_Forw_test_R1 = 0, Motor_Forw_test_R2 = 0;
void TIM7_IRQHandler()
{

    static u16 time_1ms;
    static u16 time_5ms;
    static u16 time_10ms;
    static u16 time_25ms;
    static u16 time_50ms;
    static u16 time_200ms;
    static u16 time_500ms;
    static u16 time_1000ms;
    static u16 time_1500ms;
    static u16 time_zuowu;
    static u16 lamp_1000ms;

    if(TIM_GetITStatus(TIM7, TIM_IT_Update) == SET) //溢出中断
    {
        if(flag_mission_start == 1)		//按键按下后1、5、10、50ms的任务才能进行
        {
            time_1ms++;
            time_5ms++;
            time_10ms++;
            time_50ms++;
        }

        //下面的则不受按键的影响
        time_25ms++;


        if(flag_delay_200ms)								//延时专用
        {
            time_200ms++;
        }

        if(flag_delay_500ms)
        {
            time_500ms++;
        }

        if(flag_delay_1000ms)
        {
            time_1000ms++;
        }

        if(flag_delay_1500ms)
        {
            time_1500ms++;
        }

        if(flag_delay_zuowu)
        {
            time_zuowu++;
        }

//----------------------------------------------------------------------
        if(time_1ms == 1)
        {
            time_1ms = 0;

        }

//----------------------------------------------------------------------
        if(time_5ms == 5)
        {
					time_5ms = 0;
					Detect_Flag_Step();				//判断运行到第几步了

					Detect_Flag_Mv();
					flag_delay = (flag_delay_200ms || flag_delay_500ms || flag_delay_1000ms);

					if(!flag_delay)						//在不需要延时的时候才运行下面的步骤
					{
							Detect_Flag_Slowdown();		//判断是否需要减速
							Select_Servo_Angle();			//根据步数选择舵机基本角度
							Select_Motor_Speed();			//根据步数选择电机基本速度
							Select_PID();							//根据当前运行的步数来选择用那个PID

							Servo_Set_Angle();				//设置舵机角度
							Motor_Set_Speed();				//设置电机转速

							if(!flag_huanlong)
							{
									TIM5->CNT = 0;
									TIM3->CNT = 0;
									Encoders.disA = 0;
									Encoders.disB = 0;
							}

							if(flag_huanlong)
							{
									Read_Encoder_Cnt();
							}
					}
					if(!flag_delay)
					{
						if(flag_huanlong&&!flag_chulong)
						{
							HuanLong();								//换垄，当换完垄后，flag_step会+1
						}

						if(flag_chulong)
						{
							ChuLong();
						}
					 }

        }
//----------------------------------------------------------------------
        if(time_10ms == 10)
        {
          time_10ms = 0;
					sprintf(PIDOUT,"%f\n",yaw);
//					sprintf(PIDOUT,"%f\n",ultra_F1.DIS);
//					sprintf(PIDOUT,"%f,%f\n",ultra_F1.DIS,yaw);
//					sprintf(PIDOUT,"%f,%f\n",ultra_L1.DIS,ultra_L2.DIS);
					USART1_DMATransfer((uint32_t *)PIDOUT,strlen(PIDOUT));
        }

//----------------------------------------------------------------------
        if(time_25ms == 25)
        {
            time_25ms = 0;

            Ultra_Trig();
						//Yaw_new();
        }

//----------------------------------------------------------------------
        if(time_50ms == 50)
        {
            time_50ms = 0;
        }

//----------------------------------------------------------------------
        if(time_200ms == 200)
        {
            time_200ms = 0;

            flag_delay_200ms = 0;
        }

//----------------------------------------------------------------------
        if(time_500ms == 450)
        {
            time_500ms = 0;

            flag_delay_500ms = 0;
        }

//----------------------------------------------------------------------
        if(time_1000ms == 250)	//250	//换垄时停止的时间
        {
            time_1000ms = 0;

            flag_delay_1000ms = 0;
        }
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

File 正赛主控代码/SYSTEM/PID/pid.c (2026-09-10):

#include "pid.h"
#include "math.h"
#include "motor.h"
#include "control.h"

#define n 1
#define speed_r_l 100
#define speed_r 80
#define speed_l 80

#define speed_r_9250 5
#define speed_l_9250 5

#define speed_r_9250_s 0.6
#define speed_l_9250_s 0.6

#define speed_r_back 120
#define speed_l_back 120

#define speed_r_j 100
#define speed_l_j 100

#define speed_r_r 100
#define speed_l_r 100

//电机A和电机B的转速闭环PID
PidObject PID_PWMA;
PidObject PID_PWMB;

//直走时的9250闭环
PidObject PID_9250_Forward;
PidObject PID_9250_Forward_motor;
//向右走的9250闭环
PidObject PID_9250_Right;
//向左走的9250闭环
PidObject PID_9250_Left;
PidObject PID_9250_Left_Last;

//降速向右走的9250闭环
PidObject PID_9250_Right_slow;
//降速向左走的9250闭环
PidObject PID_9250_Left_slow;

//向后走的9250闭环
PidObject PID_9250_Back;
PidObject PID_9250_Back_motor;
//出垄的9250闭环
PidObject PID_9250_Back_last;
PidObject PID_9250_Back_last_motor;

//靠左前行时舵机进行闭环
PidObject PID_L1_For_Servo;
PidObject PID_L2_For_Servo;
//靠左后退时舵机进行闭环
PidObject PID_L1_Back_Servo;
PidObject PID_L2_Back_Servo;

PidObject PID_L1_Back_Last_Servo;
PidObject PID_L2_Back_Last_Servo;
//靠右前行时舵机进行闭环
PidObject PID_R1_For_Servo;
//靠右后退时舵机进行闭环
PidObject PID_R2_Back_Servo;
PidObject PID_R1_Back_Servo;

//舵机左行右行
PidObject PID_F1_Left_Servo;
PidObject PID_F2_Left_Servo;

PidObject PID_F1_Left_Last_Servo;
PidObject PID_F2_Left_Last_Servo;

PidObject PID_F1_Right_Servo;
PidObject PID_F2_Right_Servo;

//电机左行右行
PidObject PID_F1_Left_Motor;
PidObject PID_F2_Right_Motor;

PidObject PID_L1_For_Motor;
PidObject PID_L2_For_Motor;

//换垄时，用舵机保持和垄的固定距离
PidObject PID_Back_L_Servo;
PidObject PID_Back_R_Servo;

PidObject PID_L1_Left_Servo;
PidObject PID_R1_Right_Servo;

void PID_Init(void)
{
	PID_R1_Right_Servo.desired = R1 - R2;
	//比例
	PID_R1_Right_Servo.kp = 0.3;
	//积分
	PID_R1_Right_Servo.ki = 0;
	PID_R1_Right_Servo.integ_sep = 0;
	PID_R1_Right_Servo.dt = 0;
	PID_R1_Right_Servo.iLimit = 0;
	//微分
	PID_R1_Right_Servo.kd = 0.2;
	//输出限幅
	PID_R1_Right_Servo.outputLimit = 10;
	
	PID_L1_Left_Servo.desired = L1 - L2;
	//比例
	PID_L1_Left_Servo.kp = 0.3;
	//积分
	PID_L1_Left_Servo.ki = 0;
	PID_L1_Left_Servo.integ_sep = 0;
	PID_L1_Left_Servo.dt = 0;
	PID_L1_Left_Servo.iLimit = 0;
	//微分
	PID_L1_Left_Servo.kd = 0.2;
	//输出限幅
	PID_L1_Left_Servo.outputLimit = 10;
/*
*************************************
* 		电机A转速闭环PID参数初始化			
*************************************
*/	
	PID_PWMA.desired = 50;				//电机A的转速期望
	PID_PWMA.kp = 10;							//电机A转速闭环P
	PID_PWMA.ki = 0;
	PID_PWMA.integ_sep = 0;
	PID_PWMA.dt = 0;
	PID_PWMA.iLimit = 0;
	
/*
*************************************
* 		直走时9250PID参数初始化			
*************************************
*/	
	PID_9250_Forward.desired = 0;
	//比例
	PID_9250_Forward.kp = 0.7;	//done
	//积分
	PID_9250_Forward.ki = 0;
	PID_9250_Forward.integ_sep = 0;
	PID_9250_Forward.dt = 0;
	PID_9250_Forward.iLimit = 0;
	//微分
	PID_9250_Forward.kd = 1.25;	//done
	//输出限幅
	PID_9250_Forward.outputLimit = 6;		//6
	
	
	PID_9250_Forward_motor.desired = 0;
	//比例
	PID_9250_Forward_motor.kp = 260;	//5000：200,6000:280
	//积分
	PID_9250_Forward_motor.ki = 0;
	PID_9250_Forward_motor.integ_sep = 0;
	PID_9250_Forward_motor.dt = 0;
	PID_9250_Forward_motor.iLimit = 2000*n;
	//微分
	PID_9250_Forward_motor.kd = 150;	//100
	//输出限幅
	PID_9250_Forward_motor.outputLimit = 2800*n;	//1800
/*
*************************************
* 		右行时9250PID参数初始化
*************************************
*/
	PID_9250_Right.desired = 0;
	//比例
	PID_9250_Right.kp = 98;//80
	//积分
	PID_9250_Right.ki = 0;
	PID_9250_Right.integ_sep = 0;
	PID_9250_Right.dt = 0;
	PID_9250_Right.iLimit = 600*n;	
	//微分
	PID_9250_Right.kd = 200;	//70
	//输出限幅
	PID_9250_Right.outputLimit = 1800*n;	//800
	
	PID_9250_Right_slow.desired = 0;
	//比例
	PID_9250_Right_slow.kp = 400;
	//积分
	PID_9250_Right_slow.ki = 0;
	PID_9250_Right_slow.integ_sep = 2;
	PID_9250_Right_slow.dt = 1;
	PID_9250_Right_slow.iLimit = 600*n;
	//微分
	PID_9250_Right_slow.kd = 300;
	//输出限幅
	PID_9250_Right_slow.outputLimit = 1400*n;	//800
	
	
/*
*************************************
* 		左行时9250PID参数初始化			
*************************************
*/	
	PID_9250_Left.desired = 0;
	//比例
	PID_9250_Left.kp = 98;
	//积分
	PID_9250_Left.ki = 0;
	PID_9250_Left.integ_sep = 0;
	PID_9250_Left.dt = 0;
	PID_9250_Left.iLimit = 600*n;
	//微分
	PID_9250_Left.kd = 200;	//50
	//输出限幅
	PID_9250_Left.outputLimit = 1800*n;
	
	
	PID_9250_Left_Last.desired = 0;
	//比例
	PID_9250_Left_Last.kp = 100;
	//积分
	PID_9250_Left_Last.ki = 0;
	PID_9250_Left_Last.integ_sep = 0;
	PID_9250_Left_Last.dt = 0;
	PID_9250_Left_Last.iLimit = 600*n;
	//微分
	PID_9250_Left_Last.kd = 70;	
	//输出限幅
	PID_9250_Left_Last.outputLimit = 800*n;	//800
	
	
	PID_9250_Left_slow.desired = 0;
	//比例
	PID_9250_Left_slow.kp = 400;
	//积分
	PID_9250_Left_slow.ki = 0;
	PID_9250_Left_slow.integ_sep = 2;
	PID_9250_Left_slow.dt = 1;
	PID_9250_Left_slow.iLimit = 600*n;
	//微分
	PID_9250_Left_slow.kd = 300;
	//输出限幅
	PID_9250_Left_slow.outputLimit = 800*n;

/*
*************************************
* 		向后走时9250PID参数初始化			
*************************************
*/
/****************换垄****************/
	PID_9250_Back.desired = 0;
	//比例
	PID_9250_Back.kp = 0.72;
	//积分
	PID_9250_Back.ki = 0;
	PID_9250_Back.integ_sep = 0;
	PID_9250_Back.dt = 0;
	PID_9250_Back.iLimit = 0;
	//微分
	PID_9250_Back.kd = 1.5;
	//输出限幅
	PID_9250_Back.outputLimit = 15;
	
	
	PID_9250_Back_motor.desired = 0;
	//比例
	PID_9250_Back_motor.kp = 150;
	//积分
	PID_9250_Back_motor.ki = 0;
	PID_9250_Back_motor.integ_sep = 0;
	PID_9250_Back_motor.dt = 0;
	PID_9250_Back_motor.iLimit = 2000*n;
	//微分
	PID_9250_Back_motor.kd = 50;
	//输出限幅
	PID_9250_Back_motor.outputLimit = 1200*n;
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

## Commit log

2025-10-30 Introduction to "正赛主控代码“
    This file contains the code loaded into the main controller (F407).
2025-10-30 Introduction to "正赛作业代码"
    This file contains the code loaded into the work board (F103).
2025-10-30 Introduction to "SW文件"
    This file is a model we created using SolidWorks. We will either use a 3D printer or have it fabricated by a manufacturer using stainless steel to be mounted on a vehicle.
    [Servo_mount_V2.3mf, 不锈钢底板.DWG, 不锈钢底板.SLDPRT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]
2025-10-30 Introduction to "第十届农装PCB工程"
    This file contains PCB designs we created using JLCPCB EDA (Professional Edition) software, including the main control board, driver board, and work board.
2026-09-10 代码上传
